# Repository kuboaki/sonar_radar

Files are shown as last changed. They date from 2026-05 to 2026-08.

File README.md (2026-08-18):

# sonar_radar

2D radar scanner using LEGO SPIKE Prime + Raspberry Pi Build HAT via [libspikehat](https://github.com/kuboaki/libspikehat).

This project is developed as a **digital twin**: the same application code
(`raspi/sonar_radar.py`) runs either on the real hardware or in a MuJoCo
simulation (`sim/sonar_radar_sim.py` + `libspikehat_sim`), so new behavior
can be developed and tuned in simulation before running it on the real robot.

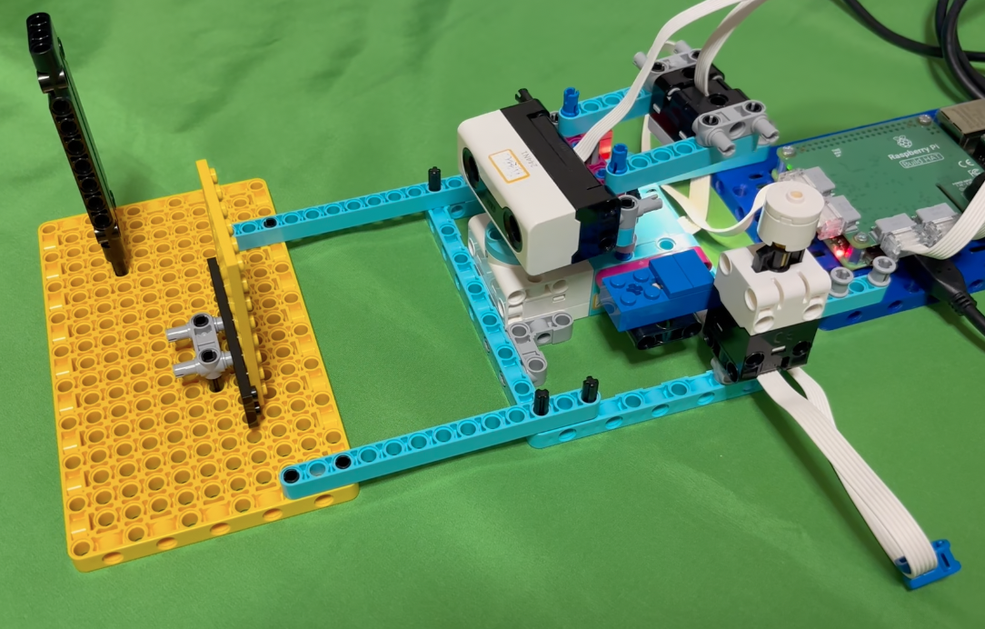
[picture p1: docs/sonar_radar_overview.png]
sonar_radar overview


[日本語版 README](README_ja.md)

## Hardware Configuration

| Port | Device | Role |
|---|---|---|
| A (0) | SPIKE Prime L Angular Motor | Dome rotation (1:3 reduction gear, direction-reversed) |
| B (1) | SPIKE Prime Force Sensor | Scan stop switch |
| C (2) | SPIKE Prime Color Sensor | End-stop marker detection (green = left end, blue = right end) |
| D (3) | SPIKE Prime Distance Sensor | Obstacle measurement |

### Rotation Markers

- **Green marker** — left end (negative direction) (formerly red; changed 2026-08-11 after real-hardware
  measurements showed hue chattering near the threshold and false-positive detection against a brown
  chassis part)
- **Blue marker** — right end (positive direction)

The dome scans back and forth, reversing direction whenever it detects either marker,
until the force sensor (stop switch) is pressed.

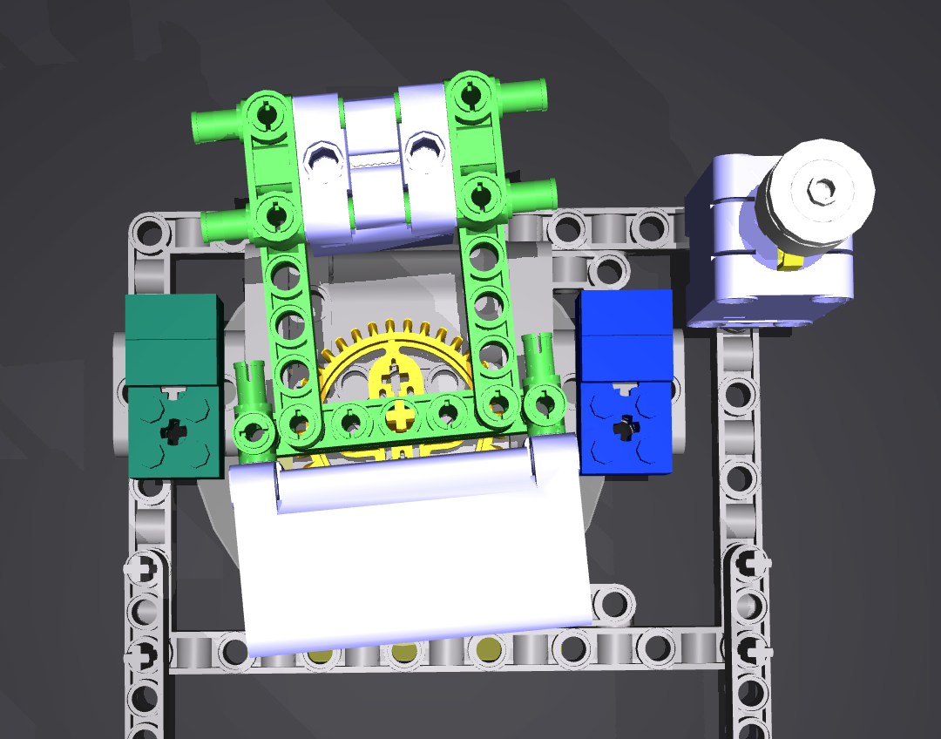
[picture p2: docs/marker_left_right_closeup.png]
Marker mechanism close-up: green marker at the left end, blue at the right end


## Scan Specification

| Parameter | Value |
|---|---|
| Sampling interval | 50 ms |
| Valid distance | 50–300 mm |
| Origin (0°) | Front center (calibrated at startup) |

## Running on the Real Hardware

- Raspberry Pi 4 + Build HAT
- **Raspberry Pi OS Bookworm (64-bit)**
- [libspikehat](https://github.com/kuboaki/libspikehat) built and installed
- `python3-build-hat` installed (`sudo apt install python3-build-hat`)

```bash
cd raspi
bash run.sh
```

`run.sh` loads the Build HAT firmware before running `sonar_radar.py`.
Avoid calling `sonar_radar.py` directly.

## Running in Simulation (MuJoCo)

- macOS / Linux with `mujoco` and `libspikehat_sim` installed (see `sim/libspikehat_sim/`)
  - **Important**: the `mujoco` pip package version must match `/Applications/MuJoCo.app`.
    A version mismatch causes a crash in `mj_ray` due to `mjModel` ABI incompatibility.
    Example: MuJoCo.app 3.10.0 → `pip install mujoco==3.10.0`, then rebuild `libspikehat_sim`.
- For viewer mode on macOS, use `mjpython` (required by MuJoCo's passive viewer)

```bash
cd sim
python3 sonar_radar_sim.py            # batch run (prints JSON result to stdout)
mjpython sonar_radar_sim.py --viewer  # with 3D viewer, real-time
```

`sonar_radar_sim.py` injects a simulated `spikehat` module backed by MuJoCo
and then runs `raspi/sonar_radar.py` unmodified — any change made to
`sonar_radar.py` is immediately reflected in the simulation. The simulation
always runs at real-time speed (`--speed 1.0`, fixed) so its behavior can be
compared directly against the real hardware.

The viewer's left UI panel is hidden by default for a cleaner view; interact
with the simulation using keyboard shortcuts instead: `Space` presses the
start/stop switch, `1`/`2` select the yellow/black obstacle wall, and the
arrow keys move the selected wall (left/right = X, up/down = Y). See
[mujoco_model/studio_to_mujoco.md](mujoco_model/studio_to_mujoco.md) for how
the MuJoCo model itself is built from the Bricklink Studio design.

#### Non-interactive run (automatic button injection)

Use `--auto-start` / `--auto-stop` to run the full scan without pressing the
physical force sensor — useful for CI and scripted testing:

```bash
# start 0.5 s after calibration, stop 3 s after start
python3 sim/sonar_radar_sim.py --auto-start 0.5 --auto-stop 3

# accelerated: 200× real-time for quick smoke tests
SPIKEHAT_SIM_SPEED_SCALE=200 python3 sim/sonar_radar_sim.py --auto-start 0.5 --auto-stop 3
```

| Option | Description |
|---|---|
| `--auto-start SEC` | Inject start button SEC seconds after calibration completes |
| `--auto-stop SEC`  | Inject stop button SEC seconds after scan start |

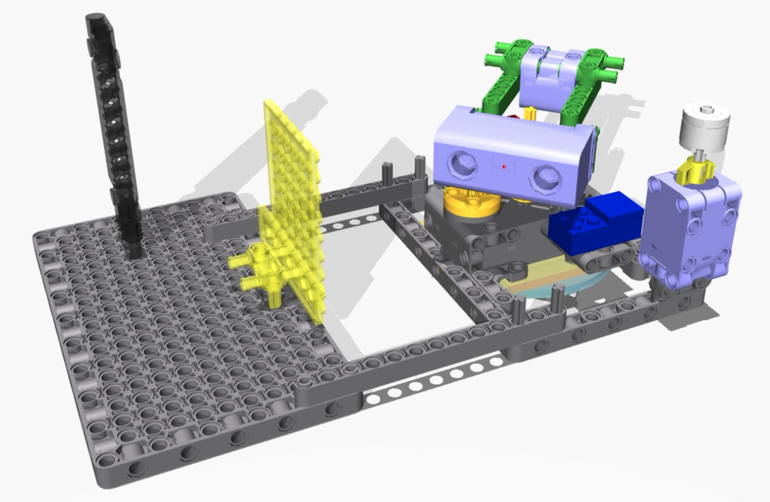
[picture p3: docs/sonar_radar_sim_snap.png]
シミュレーション実行中


*シミュレーション実行中*

## Output

JSON array to stdout, log to stderr:

```json
[
  {"angle": 12, "dome_angle": -4.0, "distance_mm": 136},
  {"angle": 15, "dome_angle": -5.0, "distance_mm": 135},
  {"angle": 21, "dome_angle": -7.0, "distance_mm": null},
  ...
]
```

- `angle` — motor encoder angle (degrees, relative to calibrated zero)
- `dome_angle` — dome angle (degrees, `angle / -3`)
- `distance_mm` — `null` when no object is detected within the valid range

## Visualization

`raspi/sonar_plot.py` reads the JSON output and plots `dome_angle` vs
`distance_mm` as a fan-shaped polar plot and a line plot, overlaying each
back-and-forth scan pass in a different color:

```bash
python3 raspi/sonar_radar.py > scan.json
python3 raspi/sonar_plot.py scan.json -o scan_result.png --title "scan result"
```

| Real hardware (`docs/scan_real.json`) | Simulation (`docs/scan_sim.json`) |
|---|---|
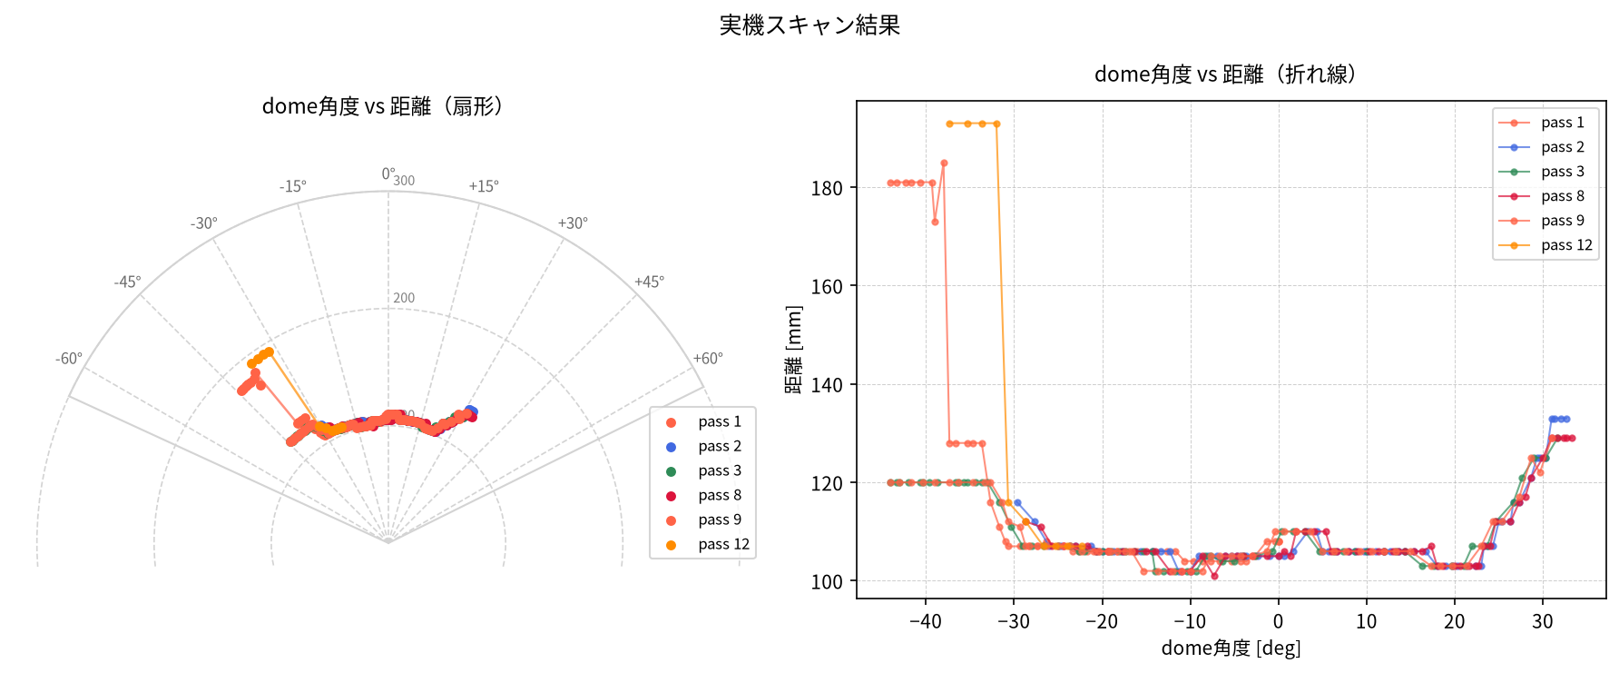
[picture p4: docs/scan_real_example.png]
real scan example
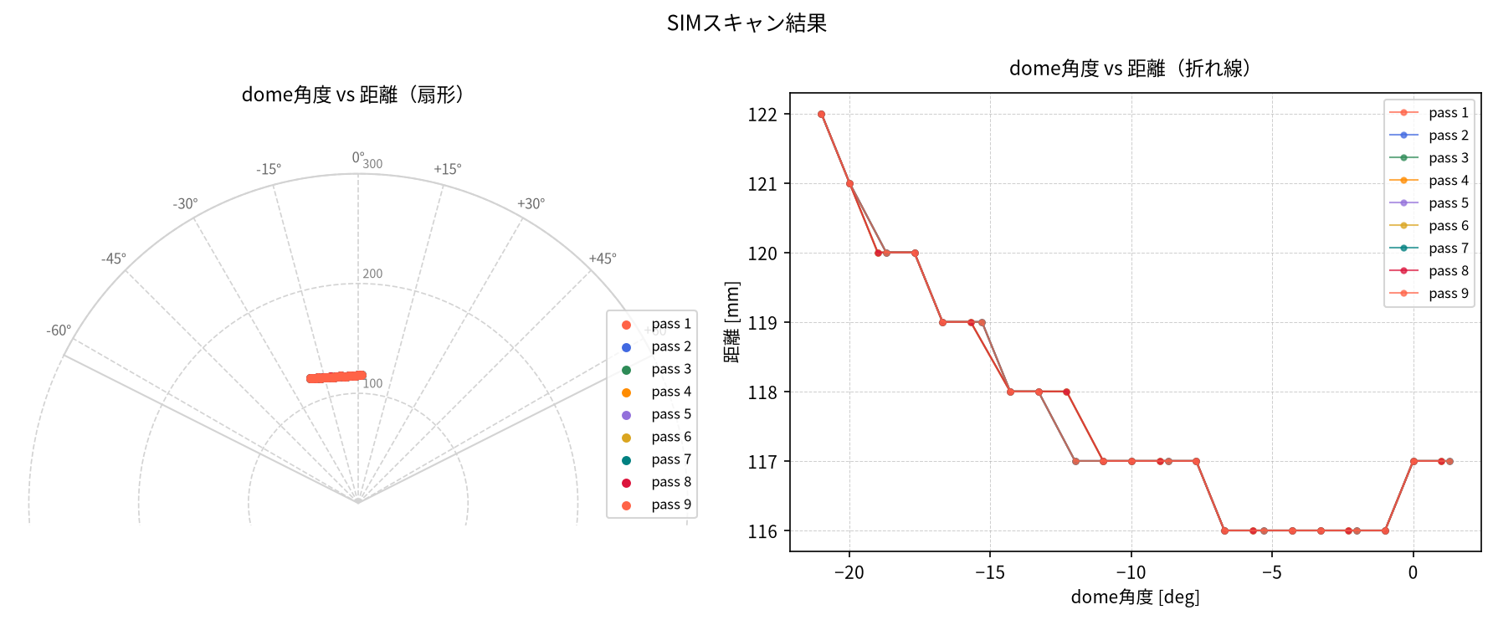
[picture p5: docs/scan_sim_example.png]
sim scan example
|  |  |

The real ultrasonic distance sensor has a wide beam, so it detects the wall
across a wide angular range (roughly -45° to +35° here). The simulated
distance sensor uses a single raycast, so it only detects the wall in a
narrow angular range directly in front (roughly -21° to +1° here). This FOV
discrepancy between the real sensor and the simulation is a known, currently
unaddressed difference (see [mujoco_model/studio_to_mujoco.md](mujoco_model/studio_to_mujoco.md)).

See [docs/visualization.md](docs/visualization.md) for the procedure used to
collect the real/sim scan data and generate these plots.

## Calibration

On startup, the motor moves to its mechanical zero position, then rotates by
`SENSOR_HOME_OFFSET` to compensate for the gear meshing offset, so that the
dome faces front (0°). No manual pre-positioning is required.

## Project Structure

```
sonar_radar/
├── raspi/                  Real-hardware app (run on Raspberry Pi)
│   ├── sonar_radar.py    Main scanner script (shared with simulation)
│   └── run.sh              Startup script (loads firmware + runs scanner)
├── sim/                     MuJoCo simulation
│   ├── sonar_radar_sim.py  Entry point that runs sonar_radar.py via libspikehat_sim
│   └── libspikehat_sim/    MuJoCo-based simulation library (libspikehat API)
├── mujoco_model/            MuJoCo model (XML, meshes, Blender export scripts)
│   └── studio_to_mujoco.md  Bricklink Studio → MuJoCo model build guide
├── studio_model/            Bricklink Studio model files
└── docs/                    Documentation images
```

## License

MIT License

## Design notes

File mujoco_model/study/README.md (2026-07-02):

# study/ — センサーコンポーネント include 方式への移行検討資料

このディレクトリには、distance_sensor および color_sensor を
libspikehat_sim の `<include>` コンポーネント方式に移行するにあたり
作成した検討・検証用の MuJoCo モデルを保存しています。

同様の作業を新しいプロジェクトで行う際の参考にしてください。

---

## 背景と問題意識

### インライン版の問題

移行前は、センサーの `<inertial>` / `<geom>` / `<site>` を
sonar_radar.xml に直接書く「インライン版」を使っていた。

インライン版の欠点:
- 複数モデルで同じセンサーを使う場合に XML が重複する
- センサー仕様が変わったときに全モデルを手修正する必要がある
- STL の座標系規約がモデルごとに異なり、位置合わせが困難になる

### include 方式の採用

libspikehat_sim の `examples/components/` 以下に
`distance_sensor_body.xml` / `color_sensor_body.xml` を置き、
利用側モデルは `<include file="..."/>` で取り込む方式に統一した。

---

## MuJoCo `<include>` の重要な挙動

MuJoCo の `<include>` は **ルート `<body>` タグを除去** し、
その子要素（`<inertial>` / `<geom>` / `<site>`）のみを
親 body に挿入する。

```xml
<!-- color_sensor_body.xml の内容 -->
<body name="color_sensor" euler="-90 0 0">   ← このタグは除去される
  <inertial .../>
  <geom .../>
  <site .../>
</body>
```

```xml
<!-- 利用側モデル -->
<body name="color_sensor" pos="X Y Z" euler="-90 0 0">  ← euler はここに書く
  <include file=".../color_sensor_body.xml"/>
</body>
```

**euler や joint は必ず外側の body に書くこと。**
コンポーネントファイル内のルート body の euler は無視される。

---

## STL 座標系規約: pivot_origin 方式

distance_sensor / color_sensor ともに `pivot_origin` 方式を採用している。

- STL の原点 = LDraw パーツの基準点（ピボット）
- Blender でインポートする際は `.io` ではなく `.ldr` を直接インポートする
  （Studio の床スナップで Z=19.5 LDU がつくため）
- blender_export_*.py の `center_mode="pivot_origin"` で生成する

`bottom_z`（STL 底面 Z=0）方式も試みたが、
モデルによってパーツの底面定義が異なり、汎用コンポーネントに向かないため廃止。

---

## ドームの5°傾き補正

sonar_radar のドームは、LDraw ジオメトリレベルで5°傾いている
（LDraw 上のボディ配置ではなくメッシュ形状に焼き込まれている）。

そのため、ドーム上のすべてのセンサーの euler に
**親フレーム（gear36）での Rz(+5°) 前置乗算** が必要になる。

### distance_sensor の場合

`blender_export.py` の `compute_local_body_euler()` が
ドームの実姿勢を含む world 回転を計算するため、
Blender 上で5°傾きが自動的に捉えられた。

結果: `euler="0 0 -175"` （-180° + 5° の補正）

### color_sensor の場合

Blender 上での計算結果は `euler="-90 -180 0"` （5°成分なし）だった。
これはカラーセンサーの LDraw 配置がドーム傾きを陽に反映していないため。

手動で Rz(+5°) を親フレームで前置乗算して euler を再計算した:

```
R_corrected = Rz(+5°) × Rx(-90°) × Ry(-180°)
→ euler="90 5 180"  （XYZ 分解結果）
```

**注意**: Rz(+5°) を XYZ euler の Rz 成分（第3引数）に加算するだけでは誤り。
intrinsic（ボディフレーム）回転になってしまい、親フレームでの補正にならない。

---

## 検証用モデルの説明

### test_distance_include_rotation.xml

distance_sensor を `<include>` 方式で単体検証するモデル。
gear36 相当のダミー body を原点に置き、その子として
sonar_sensor を配置してビューアで向きを確認するために使った。

pos / euler は最終的に sonar_radar.xml に採用した値と異なる場合がある
（試行錯誤の途中段階のものが残っている）。

### test_old_vs_new_sensor.xml

距離センサーの「インライン版（旧）」と「include 版（新）」を
ドームメッシュと一緒に同じシーンに並べて位置を比較したモデル。

- 旧インライン版: 緑色（rgba 0.2 0.9 0.2）
- 新 include 版:  赤色（include 版は色変更できないため構造で識別）

include 版の pos をインライン版に合わせ込む作業に使った。

---

## 今後の新プロジェクトへの適用手順

1. Studio でロボットモデルにセンサーを配置した `.io` を作成
2. Blender で `.ldr`（Studio 床スナップ対策、手動で Z=0 維持）をインポート
3. `blender_export_*.py` を実行して STL と pos/euler を取得
4. 利用側モデルで outer body に pos/euler を設定し `<include>` を挿入
5. ドーム等の傾きがある場合は親フレームでの回転補正を手計算で追加
6. ビューアで視覚確認し、site（黄色球）が検出面から見えることを確認

詳細は `libspikehat_sim/docs/` も参照すること。

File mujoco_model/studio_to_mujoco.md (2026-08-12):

# Bricklink StudioのモデルをMuJoCoで使う

## 概要

Bricklink Studioで作成したLEGOモデルをMuJoCo物理シミュレーターで使うための手順をまとめる。
ここでは、ソナーレーダーモデル（`sonar_radar`）を例に説明する。

```
Studio (.io) → Blender → STLメッシュ → MuJoCo XML（配置調整）→ Control割り当て → ビューア設定
```

最終的な目的は「実機の開発をシミュレータ上のコード(`raspi/sonar_radar.py`)で行い、
そのコードをそのまま実機(`libspikehat`)に持っていって動かす」こと。
そのためMuJoCoモデル側は、`libspikehat_sim` が要求するjoint/site/sensor構成
（[9. libspikehat_simとの連携](#9-libspikehat_simとの連携)参照）に適合させる必要がある。

---

## 1. Bricklink Studioでモデルを作成する

### 1.1 サブモデルの設計方針

MuJoCoで扱いやすくするため、Studioのモデル設計時に以下の点を考慮する。

**可動部はサブモデルに分ける**

MuJoCoのジョイント（関節）は body の階層で表現する。Studioでも同様に、動く部分を別サブモデルとして分離しておく。

例：
- `radar_base` … 台座（固定）
- `radar_dome` … ドーム一式（旋回する）
- `bevel_gear_12` … モーター側の12Tベベルギア（旋回する）

**色を使う部分（マーカーなど）もサブモデルに分ける**

MuJoCoのSTLメッシュは単色しか指定できない。複数色を再現するには、色ごとにSTLを分けてgeomを複数定義する必要がある。そのため、色の異なるパーツは別サブモデルとして分離しておく。

例：
- `marker_left` … 左限界マーカーブロック（`39789.dat` + ブッシュ `3713.dat`）。検出時にドームは左限界(9時方向)を向いている
- `marker_right` … 右限界マーカーブロック（`39789.dat` + ブッシュ `3713.dat`）。検出時にドームは右限界(3時方向)を向いている

> **命名は色ではなく機能(検出時のドーム旋回限界)を基準にする。** `sonar_radar09`までは`marker_red`/`marker_blue`という色ベースの命名だったが、実機実測(2026-08-11)でマーカー色を赤→緑に変更した際、色名と実際の色が食い違う問題が起きた。`sonar_radar10`で`marker_left`/`marker_right`(色を検出したときにドームがどちらの旋回限界にいるかを表す)へリネームし解消した。マーカー自体の物理的な設置位置(左/右)ではなく、検出結果としての意味(旋回限界)を基準にしている点に注意(12時方向を超音波センサー正面としたとき、緑マーカーは3時側=物理的には右に設置されているが、緑を検出する = ドームが9時側=左限界にある、という対応)。

> **注意：** Studioでは単一ブロックのサブモデルは作成できない。ブッシュなど固定パーツと組み合わせてサブモデルにする。

**ギアでつながる回転部品は、それぞれ独立したサブモデルにする**

`sonar_radar07` では、モーター側の12Tベベルギア（`bevel_gear_12`）とドーム側の36Tベベルギア
（ドーム一式に内包）が別々に回転する。MuJoCo側ではこれを2つの独立したhinge jointとし、
`equality`制約でギア比・回転方向を結びつける（[6.3](#63-equality制約によるギア連動)参照）。
そのため、Studio側でもこの2つを別サブモデルとして分離しておく。

> 旧版（`sonar_radar06`）ではモーター本体とローターを一体のカスタムパーツ
> （`motor_body`/`motor_rotor`）として作成していたが、現行版ではモーター本体側の
> メッシュは `libspikehat_sim/examples/test_motor.xml` 側に切り出され、
> `sonar_radar.xml` には含まれない。

### 1.2 サブモデルの構造例（sonar_radar10）

```
sonar_radar10.io
├── radar_base          … 台座グレーパーツ
│   ├── marker_right    … 右限界マーカー（サブモデル。命名基準は1.1節参照）
│   │   ├── 3713.dat    … ブッシュ（グレー）
│   │   └── 39789.dat   … マーカーブロック（青）
│   └── marker_left     … 左限界マーカー（サブモデル）
│       ├── 3713.dat    … ブッシュ（グレー）
│       └── 39789.dat   … マーカーブロック（緑）
├── radar_dome          … ドーム一式（36Tベベルギア32498.dat、距離/カラーセンサー含む）
├── bevel_gear_12       … モーター側12Tベベルギア（旋回軸=このサブモデル原点）
├── obstacle_wall_a     … 障害物壁A（黄色、独立サブモデル）
└── obstacle_wall_b     … 障害物壁B（黒、独立サブモデル）
```

---

## 2. Blenderの準備

### 2.1 使用するアドオン

**ldr_tools_blender**（by ScanMountGoat）

- リポジトリ：https://github.com/ScanMountGoat/ldr_tools_blender
- LDraw形式（`.ldr`、`.mpd`）およびBricklink Studioの `.io` ファイルをBlenderにインポートするアドオン
- Blender 4.1以降に対応（リリースはBlenderのPythonバージョンに紐付き）
- Rustベースの高速実装

**インストール手順：**

1. GitHubの [Releases](https://github.com/ScanMountGoat/ldr_tools_blender/releases) ページから使用しているBlenderバージョンに対応したzipをダウンロード（zipは展開しない）
2. Blenderを起動し、`Edit → Preferences → Add-ons → Install` を開く
3. ダウンロードしたzipファイルを選択してインストール
4. アドオン一覧で `ldr_tools_blender` を検索してチェックを入れて有効化

> **アップグレード時の注意：** 旧バージョンをアンインストールしてから新バージョンをインストールする必要がある。

### 2.2 デフォルトオブジェクトの削除

Blenderを新規起動すると、デフォルトでカメラ・ライト・キューブが挿入されている。ioファイルをインポートする前に、これらをすべて削除しておく。

```
Edit → Delete All（またはシーン内のオブジェクトをすべて選択してDelete）
```

### 2.3 アドオンの設定（ldr_tools_blender）

`File → Import → LDraw` を選択すると、ファイルダイアログの左側にインポートオプションパネルが表示される。以下の項目を設定する。

#### LDraw Library（LDrawライブラリのパス）

LDrawパーツライブラリの場所を指定する。Studioのアプリケーションフォルダ内のものをそのまま使用できるため、別途ダウンロードは不要。

- Mac: `/Applications/Studio 2.0/ldraw`

#### Additional Library Path（追加ライブラリのパス）

Studioで作成したカスタムパーツ（モーターローターなど）の格納場所を指定する。

- Mac: `/Users/<ユーザー名>/.local/share/Stud.io/CustomParts/`

> Macでは `.local` は隠しディレクトリのためFinderでは非表示。パス入力欄に直接入力する。
>
> **注意（2026-08-12訂正）**: アプリのサポートフォルダ名は`Studio.io`ではなく`Stud.io`（`i`の後にピリオドが入らない）。誤ったパス（存在しないディレクトリ）を指定すると、カスタムパーツ（モーターローター等）が無言でスキップされ、インポート後のBlenderシーンにモーターが表示されない、という気づきにくい壊れ方をする（エラーダイアログ等は出ない）。「モーターが消えた」と感じたら、まずこのパス設定を確認すること。

#### その他のパラメータ

| パラメータ | 設定値 | 備考 |
|---|---|---|
| Instance Type | **Linked Duplicates** | 同種パーツがメッシュを共有し軽量化される |
| Stud Type | **Normal** | 標準のスタッド形状 |
| Resolution | **Low** | ポリゴン数を抑える（MuJoCo用途では十分） |
| Gap Between Parts | **チェックあり** | パーツ間に微小な隙間を入れる（実物に近い見た目） |
| Scale | **1.0** | スケール変換はエクスポートスクリプト側で行うため、Blender上は原寸のまま |

> **Scaleを1.0にする理由：** Blenderインポート時にスケールを変えると `matrix_world` による頂点座標変換が複雑になる。エクスポートスクリプト内で `SCALE = 0.0004`（LDU→メートル）を適用するため、Blender上は原寸（LDU単位）のまま扱う。

---

## 3. BlenderへのioファイルのインポートとSTL生成

### 3.1 インポート手順

1. Blenderを起動し、デフォルトオブジェクトを削除
2. `File → Import → LDraw` で `.io` ファイルを選択
3. Scale=1 でインポート
4. アウトライナーでサブモデルの階層構造を確認

### 3.2 インポート後のオブジェクト階層

インポートすると、Studioのサブモデル構造がBlenderのオブジェクト階層として反映される。

```
sonar_radar07.io  [EMPTY]
├── radar_base       [EMPTY]
│   ├── 32054.dat    [MESH]
│   ├── ...
│   ├── marker_right [EMPTY]
│   │   ├── 3713.dat  [MESH]
│   │   └── 39789.dat [MESH]
│   └── marker_left  [EMPTY]
│       ├── 3713.dat.001  [MESH]
│       └── 39789.dat.001 [MESH]
├── radar_dome       [EMPTY]
│   ├── 32498.dat    [MESH]  ← 36Tベベルギア（旋回軸原点）
│   ├── 37316c01.dat [MESH]  ← 距離センサー
│   ├── 37308c01.dat [MESH]  ← カラーセンサー
│   └── ...
└── bevel_gear_12    [EMPTY]
    └── ...（12Tベベルギア本体、旋回軸=このEMPTYの原点）
```

---

## 4. Blenderスクリプトによる変換（blender_export.py）

### 4.1 スクリプトの概要

`blender_export.py` をBlenderのスクリプトエディタで実行することで、MuJoCo用のSTLメッシュファイルと、
MJCFに貼り付けるためのpos値・site値をログに出力する。

### 4.2 座標変換の処理

LDraw座標系からMuJoCo座標系への変換を以下の手順で行う。

1. **ワールド座標に変換**
   `matrix_world` を使って各頂点をBlenderのワールド座標に変換する

2. **オフセット適用**
   `center_mode` に応じてオフセットを計算する（詳細は4.3）

3. **LDraw → MuJoCo座標変換 + スケール適用**
   ```python
   mj_x = -rx * SCALE   # SCALE = 0.0004 (LDU → m)
   mj_y = -ry * SCALE
   mj_z =  rz * SCALE
   ```

4. **quad → 三角形分割**
   MuJoCo（STL）は三角形ポリゴンのみ対応のため、四角形ポリゴンをfan分割する

### 4.3 オフセットの種類（center_mode）

| center_mode | 内容 | 用途 |
|---|---|---|
| `bottom_z` | XY中心化＋Z底面=0 | 単独の固定パーツ |
| `center` | XYZ中心化 | フォールバック |
| `rotor_axis` | 指定オブジェクトの原点を基準 | 旋回するパーツ（`radar_dome`, `bevel_gear_12`） |
| `shared` | 呼び出し側で計算した共通オフセットを使用 | `radar_base`（gray/red/blue で位置関係を保つ） |

`radar_dome` は `32498.dat`（36Tベベルギア）、`bevel_gear_12` はサブモデル自身の原点を
`rotor_axis_obj` として渡す。これにより、STLの原点がそのままMuJoCoの `joint` 位置（hingeの回転軸）
と一致するため、MJCF側で `body pos` を「joint位置」として扱える。

### 4.4 サブモデル境界の扱い（stop_at_empty）

`radar_base` のSTL生成時は、`marker_left`/`marker_right` のメッシュを誤って含めないよう
`stop_at_empty=True` を指定する。これにより、EMPTY（サブモデル境界）に到達したところで
再帰収集を停止する。

### 4.5 色別STL分割（radar_base）

マーカーブロックの色を再現するため、`radar_base` を3つのSTL（gray/red/blue）に分割する。
gray/red/blueの3つは、全パーツの統合bboxから計算した共通オフセット（`shared_offset`）を使う。
これにより3つのSTLの位置関係が正しく保たれ、MuJoCo上で重ね合わせたときに一致する。

### 4.6 センサーsite位置の自動計算

`radar_dome` エクスポート時、`32498.dat`（旋回軸）を基準に、距離センサー（`37316c01.dat`）と
カラーセンサー（`37308c01.dat`）のローカル座標を計算し、`<site>` タグの形でログに出力する
（`compute_local_site_pos`）。

```
<site name="sonar_site" pos="..." size="0.01" rgba="1 0 0 1"/>
<site name="color_site" pos="..." size="0.01" rgba="1 1 0 1"/>
```

これは**初期値**であり、実際にはビューアで実機の検出結果と見比べながら微調整する
（[7. センサーsiteの配置調整](#7-センサーsiteの配置調整)参照）。

### 4.7 スクリプトの実行方法

1. Blenderのスクリプトエディタで `blender_export.py` を開く
2. 「スクリプトを実行」ボタンをクリック
3. `blender_export_log.txt` で結果（オフセット値、MJCF pos、site pos、XMLスニペット）を確認

---

## 5. 生成されるファイル

### 5.1 STLメッシュファイル（meshes/フォルダ）

| ファイル | 内容 | rgba |
|---|---|---|
| `radar_base_gray.stl` | 台座グレーパーツ | `0.366 0.361 0.371 1` |
| `radar_base_left.stl` | 左限界マーカーブロック(緑検出時。旧`radar_base_red.stl`/`base_red_geom`。実機実測(2026-08-11)でチャタリング・誤検出が判明し赤→緑に変更、2026-08-12にsonar_radar10でファイル名・geom名も`left`/`right`(機能ベース)にリネーム) | `0.020 0.250 0.200 1`(HSV変換でhue≈167、実機実測のhue158〜170に整合) |
| `radar_base_right.stl` | 右限界マーカーブロック(青検出時。旧`radar_base_blue.stl`/`base_blue_geom`) | `0.000 0.089 0.515 1` |
| `radar_dome.stl` | ドーム一式（36Tベベルギア含む） | `0.2 0.5 0.2 1` |
| `bevel_gear_12.stl` | モーター側12Tベベルギア | `0.9 0.7 0.1 1` |

### 5.2 ログファイル

- `blender_export_log.txt` … 座標変換のオフセット値、MJCF posの計算結果、site pos、XMLスニペットを出力

---

## 6. MuJoCo XMLへの組み込みと配置調整

### 6.1 body階層とSTLの対応

```
Studio サブモデル        MuJoCo XML
────────────────────    ──────────────────────────────────────────
radar_base           →  <body name="radar_base">
  marker_left        →    <geom name="base_left_geom" .../>  ※同じbody内に複数geom
  marker_right       →    <geom name="base_right_geom" .../>

bevel_gear_12        →  <body name="motor_rotor">           ← motor_joint(hinge)
                            <geom name="bevel_gear_12_geom" .../>

radar_dome           →  <body name="radar_dome">            ← dome_joint(hinge)
                            <geom name="dome_geom" .../>
  37316c01.dat       →    <body name="sonar_sensor" pos="..." euler="...">
                              <include file=".../distance_sensor_body.xml"/>
                            </body>
  37308c01.dat       →    <body name="color_sensor" pos="...">
                              <geom name="color_geom" .../>
                              <site name="color_site" .../>
                            </body>
```

`motor_rotor`（12Tギア）と `radar_dome`（36Tギア）は、いずれも `radar_base` の直下に
**独立した body** として配置し、それぞれに `hinge` jointを持たせる。2つのjointは
equality制約で連動させる（[6.3](#63-equality制約によるギア連動)）。

距離センサー（`37316c01.dat`）は `libspikehat_sim` のコンポーネント
（`distance_sensor_body.xml`）を `<include>` で組み込む。
カラーセンサー（`37308c01.dat`）は現状インラインSTLのまま（今後コンポーネント化予定）。

### 6.2 配置（pos/euler）はBlender出力どおりにならない

`blender_export_log.txt` に出力されるpos値（`rotor_axis`基準で計算した値）は**初期値**であり、
そのままではビューア上でパーツ同士の噛み合いや向きがズレることが多い。
実際には以下のような**手動調整が必須**になる。

- **回転方向（axis符号）の調整**
  Studio/Blender側のZ軸回転と、MuJoCo `euler`・`joint axis` の符号の関係は自明ではない。
  「正方向に回したらどちらに動くべきか」を実機と見比べ、`joint axis="0 0 1"` /
  `axis="0 0 -1"` のどちらにするかを決める
  （[[feedback_mujoco_hinge_axis_vs_equality_sign]] 参照：符号調整は
  equality制約側ではなく hinge axis 側で行うこと）。

- **ギアの噛み合い位置の微調整**
  `motor_rotor`（12T）と `radar_dome`（36T）はそれぞれ別サブモデルとしてエクスポートされた
  原点を基準に配置するが、Studio上の組み立て位置によっては数度ズレた状態でしか噛み合わない
  （sonar_radar07では実測5度のズレがあった）。この機構的なズレは
  `raspi/sonar_radar.py` 側の `SENSOR_HOME_OFFSET` で補正し、**MuJoCoモデル自体は
  組み立て可能な位置であればよい**、という方針にしている。

- **dome本体の位置(pos)**
  `radar_dome` の `pos` は、`bevel_gear_12`（motor_rotor）の旋回軸との相対位置になるよう
  ビューアで動かしながら微調整する。現在値は `pos="-0.0083 0.0007 0.0358"`。

### 6.3 equality制約によるギア連動

12T-36Tベベルギアの噛み合い（ギア比1:3、回転方向反転）は、2つのhinge jointを
`equality`制約の `polycoef` で結びつけて表現する。

```xml
<equality>
  <!-- ベベルギア(12T-36T)噛み合い: dome_joint = +motor_joint / 3
       motor_joint axis="0 0 -1"(正=CW), dome_joint axis="0 0 1"(正=CCW)
       CWモーターに対してCCWドーム → polycoef正 -->
  <joint joint1="dome_joint" joint2="motor_joint" polycoef="0 0.33333333 0 0 0"/>
</equality>
```

**motor/dome の axis 設定（sonar_radar08 実機確認済み）:**

| joint | axis | 正方向の意味 |
|---|---|---|
| `motor_joint`（12T, motor_rotor） | `0 0 -1` | 正 = CW（時計回り）= 実機の正エンコーダ方向 |
| `dome_joint`（36T, bevel_gear_36） | `0 0 1` | 正 = CCW（反時計回り）= 実機の正PWM時のドーム旋回方向 |

実機確認：正PWM → エンコーダ正 → モーターCW → ドームCCW（ベベルギアで逆転）。

> **回転方向の調整は `axis` で行う。** `polycoef` の符号を変えて回転方向を反転させると、
> 一見動くが速度比などで不整合が生じることがある。回転方向の反転は
> `<joint ... axis="0 0 -1" .../>` のように joint の `axis` 側で行い、
> `polycoef` はギア比（絶対値）のみを表す、という分担にする。

### 6.4 衝突ガードジオム

壁がモーター柱やドーム旋回範囲に侵入しないよう、`radar_base` body に薄いスラブ型
ガードジオムを追加する。

```xml
<!-- 高さ4mm（Z=0〜4mm）の薄スラブにして、センサーのレイキャスト高さ（30mm以上）に干渉しない -->
<geom name="radar_column_guard" type="box"
      pos="0.008 0.060 0.002" size="0.030 0.030 0.002"
      contype="1" conaffinity="1" rgba="0.9 0.5 0.1 0.3"/>
<geom name="dome_sweep_guard" type="cylinder"
      pos="0.0076 0.0728 0.002" size="0.040 0.002"
      contype="1" conaffinity="1" rgba="0.5 0.8 0.9 0.3"/>
```

> ガードを全高のboxやcylinderにすると `mj_ray`（NULL geomgroup）がセンサーレイキャストの
> 対象に含まれてしまい、カラーセンサーがマーカーより先にガードに当たる問題が発生する。
> `libspikehat_sim` 側にモデル固有の geomgroup フィルタを追加してはならない
> （汎用ライブラリとしての設計原則）ため、ガード側を薄くして高さで回避する。

---

## 7. センサーsiteの配置調整

`sonar_site`（距離センサー）・`color_site`（カラーセンサー）は、4.6で自動計算した値を初期値として、
以下の手順で実機に合わせて微調整する。

1. **初期配置**: `blender_export_log.txt` 出力値をXMLに貼り付ける
2. **静止状態での距離値の確認**: dome角度0°（正面）で `sonar_site` から壁までの距離を
   simで読み取り、実機の同条件での測定値（例: 実機118mm vs sim116mm）と比較してZ/Y位置を調整
3. **マーカー検出角度の確認**: `color_site` の位置・向きにより、赤/青マーカーを検出する
   dome角度がsim/実機で一致するかを確認し、位置を微調整する
4. **ビューアでの目視確認**: site（球で表示される）が実機の対応する部品（センサーブロック）の
   位置に重なっているかを目視で確認する

site位置の調整は、6.2の本体位置(pos)調整と相互に影響するため、
「本体位置を仮決め → site位置を実測値に合わせる → 旋回させて再確認」を繰り返す。

---

## 8. Controlの割り当て

ビューアの **Control** タブから操作できるアクチュエータと、`libspikehat_sim` が参照するsensorを
以下のように対応づける。

### 8.1 actuator一覧

| actuator | joint | 種別 | 用途 |
|---|---|---|---|
| `turret_motor` | `motor_joint` | motor（トルク, gear=10） | `motor_pwm`/`motor_run_to_position` で旋回 |
| `press_ctrl` | `press_slide` | position | 終了スイッチ(`press_body`)を押す（ビューア操作用） |
| `wall_a_x_ctrl` | `wall_a_x` | position | 壁A（黄色）のX位置（ビューア操作用） |
| `wall_a_y_ctrl` | `wall_a_y` | position | 壁A（黄色）のY位置（ビューア操作用） |
| `wall_b_x_ctrl` | `wall_b_x` | position | 壁B（黒）のX位置（ビューア操作用） |
| `wall_b_y_ctrl` | `wall_b_y` | position | 壁B（黒）のY位置（ビューア操作用） |

`turret_motor` のみがアプリケーションコード（`sonar_radar.py`）から操作される。
他は**ビューアのControlタブから人間が操作する**ためのもので、実機には存在しない
sim専用のオブジェクト（壁・終了スイッチ）を動かすために用意している。

**壁のキーボード操作（sonar_radar_sim.py）:**

| キー | 動作 |
|---|---|
| `1` | 壁A（黄色）を選択 |
| `2` | 壁B（黒）を選択 |
| `←` / `→` | 選択中の壁をX方向に1スタッド（8mm）移動 |
| `↑` / `↓` | 選択中の壁をY方向に1スタッド（8mm）移動 |

MuJoCo ビューアの組み込みショートカット（A/D/W/S/F 等）と競合するため、
WASDキーは使用しない。矢印キーは `key_callback` で `_KEY_RIGHT/LEFT/UP/DOWN`
（GLFW keycode 262〜265）として取得する。

### 8.2 sensor一覧

| sensor | 種別 | 対応するlibspikehat_sim API |
|---|---|---|
| `turret_angle`/`turret_vel` | jointpos/jointvel (`motor_joint`) | `motor_get_position` |
| `dome_angle`/`dome_vel` | jointpos/jointvel (`dome_joint`) | （デバッグ用、API未使用） |
| `distance_pos`/`distance_quat` | framepos/framequat (`distance_site`) | `distance_read`（前方レイキャスト） |
| `color_pos`/`color_quat` | framepos/framequat (`color_site`) | `color_read_hsv`/`color_read_rgb`（下方レイキャスト） |
| `force_touch` | touch (`force_site`) | `force_is_pressed` |

新しい実機を作る場合も、**アプリコードが使うAPIに対応するsite/sensorは必ず用意する**
（`motor_joint` + `sonar_site` + `color_site` + `force_site` 相当）。
壁や終了スイッチのような「sim専用の操作対象」は、実機に存在しなくても
ビューア確認用に追加してよい。

---

## 9. ビューアの設定（sonar_radar_sim.py）

`sim/sonar_radar_sim.py` がMuJoCoモデルとビューアを起動するランチャー。
モデル固有の設定は主に以下の3か所に集中している。

### 9.1 初期カメラ

floor(2m四方)を含めた自動フィットだと対象（数cm）が小さく表示されるため、
本体サイズを基準にカメラを寄せる。

```python
_mdl.stat.center[:] = [0.0, -0.02, 0.03]
_mdl.stat.extent = 0.12
...
viewer.cam.lookat[:] = _mdl.stat.center
viewer.cam.distance  = _mdl.stat.extent * 2.5
viewer.cam.azimuth   = 180.0
viewer.cam.elevation = -30.0
```

新しいモデルでは、本体のだいたいの中心座標とサイズに合わせて `stat.center`/`stat.extent` を変更する。

### 9.2 表示用 qpos の反映

表示専用の `_dat` には物理演算（mj_step）を行わず、メインスレッド側 `libspikehat_sim` の
実シミュレーション状態（`hat.motor_get_position` 等）を `mj_kinematics`/`mj_comPos` で
反映するだけにする。`equality`制約はここでは評価されないため、`dome_joint` の角度も
`motor_joint` の角度から `polycoef` と同じ式で手動計算している。

```python
_motor_rad = math.radians(_hat.motor_get_position(0))
_dat.qpos[_motor_qadr] = _motor_rad
_dat.qpos[_dome_qadr]  = +_motor_rad / 3.0   # equalityのpolycoefと同じ式（符号は6.3参照）
```

新しいモデルでギア比が変わる場合は、ここの係数も `polycoef` と合わせて変更する。

### 9.3 Controlタブの操作をsimに転送

`press_ctrl`/`wall_x_ctrl`/`wall_y_ctrl` のように、ビューアのControlタブで人間が操作する
sim専用actuatorは、表示用 `_dat.ctrl` の値を毎フレーム `hat.sim_set_ctrl()` で
実シミュレーション側に転送し、結果のqposを表示用 `_dat.qpos` に反映する。

```python
_hat.sim_set_ctrl(_press_aid, float(_dat.ctrl[_press_aid]))
...
_dat.qpos[_press_qadr] = _hat.sim_get_qpos(_press_qadr)
```

壁のように複数のsim専用オブジェクトがある場合は、それぞれに同様の転送処理を追加する。
壁の移動はControlタブのスライダーに加え、キーボードコールバック（`key_callback`）からも
`_dat.ctrl` を直接書き換えることで操作できる（8.1参照）。

新しいモデルでsim専用の可動オブジェクトを追加する場合は、対応するactuator/jointの
id取得とこの転送処理を追加する。

### 9.4 実行速度（speed_scale）

`--speed` のデフォルトは **1.0（実時間）固定**。実機の動作時間とsimの動作時間を
直接比較できることが本プロジェクトの前提のため、デフォルト値は変更しない
（[[feedback_sonar_radar_realtime_sim]] 参照）。

---

## 10. libspikehat_simとの連携

### 10.1 概要

`libspikehat_sim` は `libspikehat` と同じAPIを持つMuJoCo版シミュレーターライブラリ。
`sonar_radar.xml` に上記のsite/sensor/actuatorを用意することで、
`raspi/sonar_radar.py` をそのままsimで動かせる。

```
実機（Raspberry Pi）:  raspi/sonar_radar.py → libspikehat     → Build HAT → SPIKE Prime
シム（Mac/Linux）   :  raspi/sonar_radar.py → libspikehat_sim → MuJoCo   → mujoco_model/sonar_radar.xml
```

### 10.2 sonar_radar_sim.py の仕組み

`sim/sonar_radar_sim.py` が `libspikehat_sim` の `SpikeHat` を `spikehat.SpikeHat` として
`sys.modules` に差し込み、`raspi/sonar_radar.py` を `importlib` で `__main__` として実行する
（ファイルのコピーではなく、`raspi/sonar_radar.py` を直接参照する）。

### 10.3 実行方法

```bash
cd sonar_radar/sim
python3 sonar_radar_sim.py                 # バッチ実行（実時間）
mjpython sonar_radar_sim.py --viewer       # ビューア付き（推奨、実時間）
```

`SPIKEHAT_SIM_XML` 環境変数でXMLパスを上書きできる（デフォルトは
`mujoco_model/sonar_radar.xml`）。

### 10.4 libspikehat_sim コンポーネントの include と可動部アタッチメント

#### MuJoCo `<include>` の制約

MuJoCo の `<include>` はXMLを**そのまま埋め込む**仕組みであり、
Unreal Engine や Unity のようなコンポーネントシステムとは異なる。
include 内で定義されたボディに、include を利用する側から**子ボディを追加することはできない**。

```xml
<body name="sensor_mount">
  <include file=".../force_sensor_body.xml"/>
  <!-- force_sensor_body.xml の中にある button body に、
       ここから子ボディを追加することはできない -->
</body>
```

#### include に適したコンポーネント

外部パーツが可動部に接続**しない**センサー類は include に適している。

| コンポーネント | include 適合 | 理由 |
|---|:---:|---|
| `distance_sensor_body.xml` | ✓ | ドームに取り付くだけ（可動部への接続なし） |
| `color_sensor_body.xml` | ✓ | 同上 |
| `force_sensor_body.xml` | △ | button body に press_block が接続する |

#### 可動部に外部パーツを接続する場合

press_block（シャフトを含む）のように、コンポーネント内の可動ボディに**剛体結合**する
外部パーツは、MuJoCo の `weld` equality + tight solref で近似する。

```xml
<!-- press_block を button に剛体結合（include の制約によりボディ階層での表現不可） -->
<equality>
  <weld body1="press_block" body2="button" solref="0.001 1"/>
</equality>
```

- `solref="0.001 1"` はデフォルト (`0.02 1`) より大幅に拘束を強め、残差を最小化する。
- 完全剛体ではないため、高速・高荷重の用途には注意が必要。

#### インライン展開による回避

どうしても親子階層で剛体結合する必要がある場合は、
include を使わず force_sensor_body.xml の内容を利用側XMLにインライン展開し、
press_block を button ボディの子として直接定義する。

```xml
<body name="button" pos="0 0 0">
  <joint name="button_slide" .../>
  <geom name="button_geom" .../>
  <body name="press_block" pos="...">   <!-- シャフトごと button の子として定義 -->
    <inertial .../>
    <geom name="press_geom" .../>
  </body>
</body>
```

この場合、force_sensor_body.xml の更新を手動でインライン版に反映する必要がある。

---

## 11. Studioモデルを変更したときの影響範囲

Studioモデルを変更した場合、変更の種類によって必要な作業が異なる。

### 11.1 影響範囲サマリー

| 変更の種類 | STL再生成 | XML変更 | アプリコード変更 |
|---|:---:|:---:|:---:|
| 固定部品の追加・削除 | 要 | 不要 | 不要 |
| 可動部の形状変更 | 要 | 要（pos） | 不要 |
| センサーの取り付け位置変更 | 要 | 要（site） | 不要 |
| ギア比の変更 | 要 | 要（equality） | 要（3箇所） |
| 新しい可動部の追加 | 要 | 要（joint等） | 要（sim.py） |

### 11.2 変更別の作業内容

#### 固定部品の追加・削除（例：台座に飾りパーツを追加）

1. `blender_export.py` を再実行してSTLを再生成
2. `radar_base_gray.stl` 等を使い続ける場合はXML変更不要（自動反映）
3. ただし `shared_offset`（全パーツのbboxから計算）が変わるため、
   赤・青マーカー等の位置関係がずれていないかビューアで確認する

#### 可動部の形状変更（例：ドーム形状を変更）

1. 対応するSTLを再生成（例：`radar_dome.stl`）
2. `body pos` の再調整が必要になる場合あり（重心・サイズの変化による）
3. センサーsite（`sonar_site`/`color_site`）の位置を再確認・微調整
   （[7. センサーsiteの配置調整](#7-センサーsiteの配置調整)の手順を再実施）

#### センサーの取り付け位置変更（例：距離センサーの位置を変える）

距離センサーは `libspikehat_sim` のコンポーネント（`include`）として組み込んでいる。
位置変更時は以下の手順を踏む：

1. `sonar_radar09.io` でセンサーの取り付け位置・向きを変更して保存
2. Blenderで `sonar_radar09.io` をインポートし、センサー (`37316c01.dat`) と
   基準ボディ (`bevel_gear_36` 等) の `matrix_world.translation` を取得
3. `pos = -(T_sensor - T_ref) * SCALE`（mj_x,mj_y符号反転、mj_z符号そのまま）を計算
4. `sonar_radar.xml` の `sonar_sensor` body の `pos` を更新
5. `euler` は `R_sensor_world @ Rx(-90°) @ Rz(180°)` をT_conj変換して求める
   （`studio_to_mujoco.md` 付属の変換スクリプトを参照）

カラーセンサーは現状インラインSTLのため従来通り `blender_export.py` を再実行。

#### ギア比の変更（例：12T-36T → 12T-24T）

影響が最も広い。以下の3箇所を**一致させる**こと。

| ファイル | 変更箇所 | 例（1:2に変更） |
|---|---|---|
| `mujoco_model/sonar_radar.xml` | `<equality>` の `polycoef` | `"0 -0.5 0 0 0"` |
| `sim/sonar_radar_sim.py` | `_viewer_loop` 内のドーム角度計算 | `-_motor_rad / 2.0` |
| `raspi/sonar_radar.py` | `GEAR_RATIO` 定数 | `GEAR_RATIO = 2` |

> **注意：** 回転方向の反転は `polycoef` の符号ではなく `dome_joint` の
> `axis` で調整する（[[feedback_mujoco_hinge_axis_vs_equality_sign]]）。

#### 新しい可動部の追加（例：新センサーを別軸で追加）

1. Studio側でサブモデルを追加・STLを再生成
2. XMLに `<body>` / `<joint>` / `<actuator>` / `<sensor>` を追加（§6〜§8参照）
3. `sim/sonar_radar_sim.py` の `_viewer_loop` に新しいjoint/actuatorの
   id取得とqpos反映処理を追加（§9.2〜9.3参照）
4. 新センサーを `raspi/sonar_radar.py` から使う場合はアプリコードも更新

---

## 12. 変更履歴

### v0.11.0（2026-08-12）

**マーカーのサブモデル名を色ベース→機能ベースに統一（Left/Right命名統一）**

- Studio(`sonar_radar10.io`)で`marker_red`/`marker_blue`を`marker_left`/`marker_right`にリネーム。命名基準は「色を検出したときドームがどちらの旋回限界にいるか」（1.1節の注記参照。マーカー自体の物理設置位置とは対応が逆転する点に注意）。
- `blender_export.py`のオブジェクト参照・出力STLファイル名を追従（`radar_base_red.stl`/`radar_base_blue.stl` → `radar_base_left.stl`/`radar_base_right.stl`）。Blenderのヘッドレス実行（`blender --background sonar_radar10.blend --python blender_export.py`）でSTL再生成・動作確認済み。
- `sonar_radar.xml`のmesh asset名・geom名を追従（`radar_base_red_mesh`/`base_red_geom` → `radar_base_left_mesh`/`base_left_geom`、blue側も同様）。rgba値（色）自体は変更なし。
- 2026-08-11のマイルストーン7（development_log.md）で合意した「別途まとまった作業として行う」TODOの実施。

### v0.10.2（2026-07-06）

**フォースセンサーのストローク実測値への修正**

- ボタン突出量・ストロークを実測 8mm に修正（旧: 9.5mm）。
- `force_sensor_button.stl` を 8mm 突出量で再エクスポート。
- `button_slide` range 0〜0.008m、stiffness 1250 N/m（10N÷0.008m）に更新。
- `force_site` をボタン本体（可動）からセンサー本体ハウジング（固定）の Z=0.030m に移動。
  ストロークの 62% 押込み位置 = Hard-pressed 判定点。
- `press_block` pos Z を 0.0411 → 0.0405m に修正（ボタン位置変更に追従）。
- equality `solref="0.002 1"` でタイト拘束（重力残差 0.05mm 以下）。
- `libspikehat_sim` サブモジュールを b3591f1 に更新。

### v0.10.1（2026-07-05）

**ドキュメント画像を更新**

- `docs/sonar_radar_overview.png` を追加（`.jpg` から `.png` に変更）。
- `docs/sonar_radar_sim_snap.png` を更新（starter/フォースセンサーを含む最新外観）。
- `README.md` / `README_ja.md` の画像参照を `.jpg` から `.png` に変更。

### v0.10.0（2026-07-04）

**全センサーを libspikehat_sim の include コンポーネントに移行**

- 距離センサー・カラーセンサー・フォースセンサーの3つすべてを
  `libspikehat_sim/examples/components/` の `<include>` として組み込む方式に統一。
  各センサーの geom・joint・site は `sonar_radar.xml` のインライン定義から分離された。
- `blender_export.py` に `starter`（フォースセンサーユニット）の
  `sensor_mount` pos を自動計算するセクションを追加。
- カラーセンサーの `SENSOR_HOME_OFFSET` 符号修正（+5° → −5°）、
  `euler="-90 -185 0"` に更新。
- `button.stl` を `force_sensor_button.stl` にリネーム。
- `libspikehat_sim` の `force_sensor.io` の原点を
  センサー本体底面中心（LDraw 原点）に合わせた
  （`shared_offset=(0,0,0)` を確認済み）。
- `sonar_radar09.blend` を最新の Studio モデルから再生成。

### v0.9.0（2026-06-29）

**Hakoniwa asset 化・libspikehat_pdu 作成・結合テスト完了**

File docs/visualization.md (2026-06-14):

# スキャン結果の可視化手順

実機・SIMのスキャン結果を取得し、`raspi/sonar_plot.py` で可視化するまでの手順。
`docs/scan_real.json`/`docs/scan_real_example.png`、
`docs/scan_sim.json`/`docs/scan_sim_example.png` はこの手順で作成した例。

## 1. 実機データの取得

Raspberry Pi上で `raspi/run.sh` を実行し、標準出力のJSONをファイルに保存する。

```bash
cd ~/projects/sonar_radar/raspi
bash run.sh > scan_real.json
```

フォースセンサー（終了スイッチ）を押すとスキャンが終了し、JSONが出力される。
作成した `scan_real.json` を、Mac側のリポジトリの `docs/` にコピーする（`scp` 等）。

## 2. SIMデータの取得

### 2.1 注意点：バッチ実行はスキャンが終了しない

`sim/sonar_radar_sim.py` をビューアなし（`python3`）で実行すると、
フォースセンサー（`press_body`）を押す手段がないため、`do_continuous_scan` の
終了条件が満たされず、標準出力にJSONが出力されない（プロセスを止めるまで動き続ける）。

### 2.2 手順：標準エラーのログから再構成する

実用上は、標準エラー出力（`[ xx.xxs] motor:... dome:... -> ...`形式のログ）を
タイムアウト等で適当な時間だけ取得し、そこから `{"angle":..., "dome_angle":...,
"distance_mm":...}` のJSON配列を再構成すれば `sonar_plot.py` にそのまま使える。

```bash
cd sim
timeout 45 python3 sonar_radar_sim.py > /dev/null 2>sim_scan.log
```

```python
# sim_scan.log -> scan_sim.json
import re, json

results = []
pat = re.compile(r"motor:\s*([+-]?\d+)°\s*dome:\s*([+-]?\d+\.\d+)°\s*->\s*(null|\d+)\s*(?:mm)?")
for line in open("sim_scan.log"):
    m = pat.search(line)
    if not m:
        continue
    angle = int(m.group(1))
    dome = float(m.group(2))
    dist = None if m.group(3) == "null" else int(m.group(3))
    results.append({"angle": angle, "dome_angle": dome, "distance_mm": dist})

json.dump(results, open("scan_sim.json", "w"))
```

> ビューア（`mjpython sonar_radar_sim.py --viewer`）を使い、Controlタブの
> `press_ctrl` を操作してスキャンを正規に終了させれば、標準出力のJSONを
> そのまま使うこともできる。

## 3. 可視化

```bash
python3 raspi/sonar_plot.py docs/scan_real.json -o docs/scan_real_example.png --title "実機スキャン結果"
python3 raspi/sonar_plot.py docs/scan_sim.json  -o docs/scan_sim_example.png  --title "SIMスキャン結果"
```

`sonar_plot.py` は `matplotlib`/`numpy` に依存する（`pip install matplotlib`）。
日本語フォントは `Noto Sans CJK JP`（Linux）/ `Hiragino Sans`（macOS）/
`IPAGothic` のいずれかが必要。

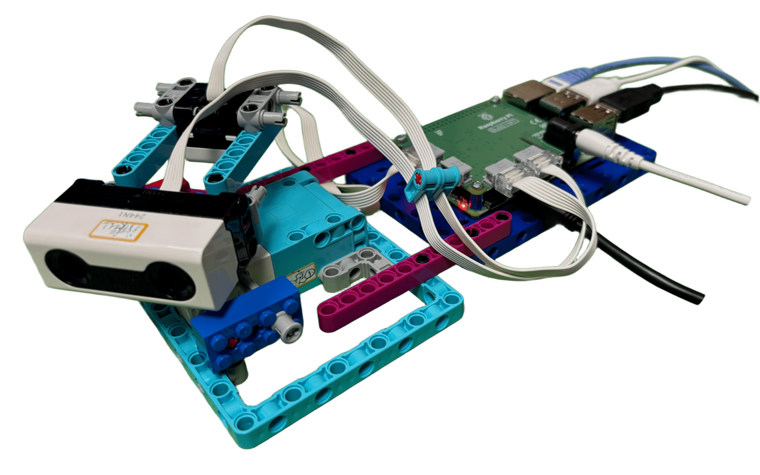
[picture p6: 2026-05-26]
docs/sonar_radar_overview.jpg

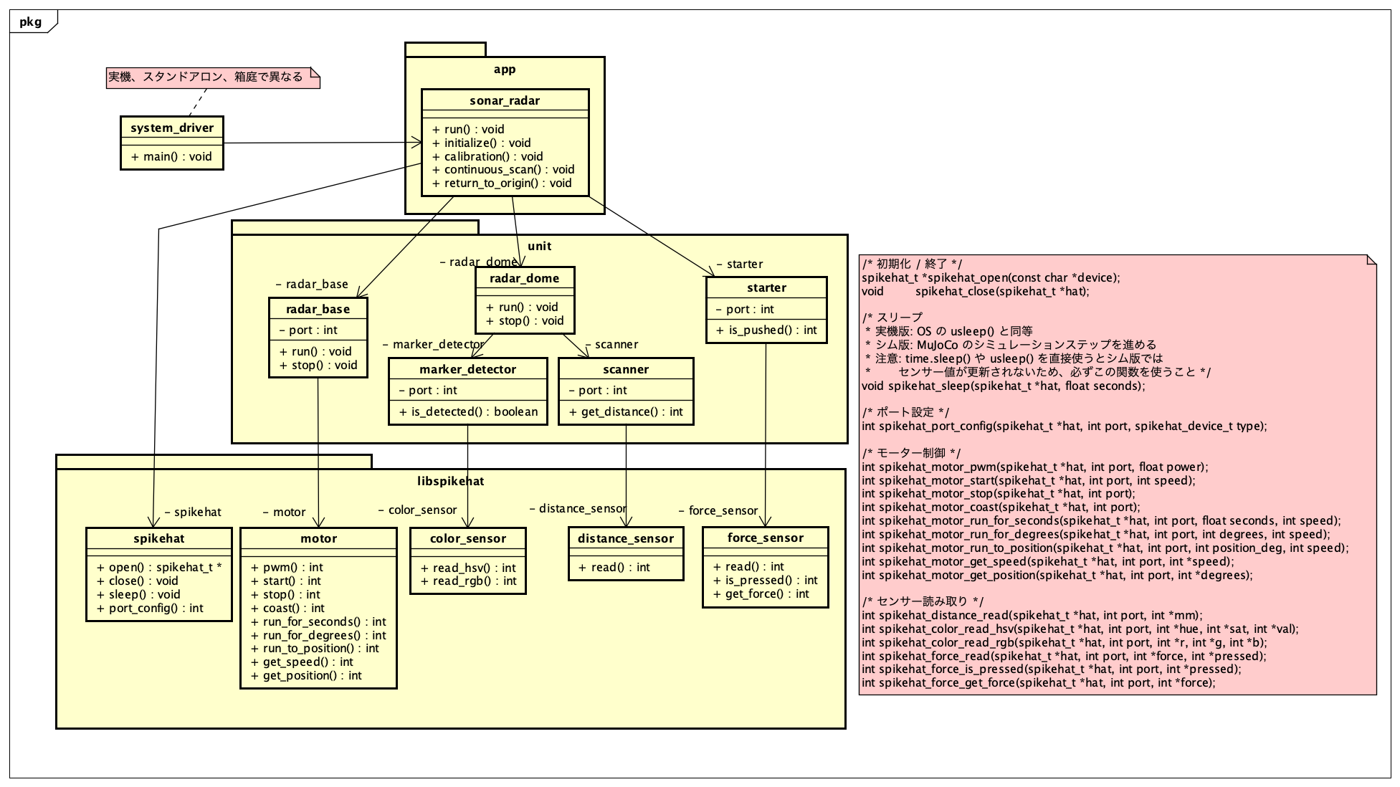
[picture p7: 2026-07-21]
asta/sonar_radarのクラス図.png

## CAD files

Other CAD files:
mujoco_model/meshes/radar_base_panel.stl
mujoco_model/meshes/radar_dome.stl
mujoco_model/meshes/radar_base_left.stl
mujoco_model/meshes/bevel_gear_12.stl
mujoco_model/meshes/bevel_gear_36.stl
mujoco_model/meshes/radar_base_gray.stl
mujoco_model/meshes/radar_base_right.stl
mujoco_model/meshes/obstacle_wall_a.stl
mujoco_model/meshes/obstacle_wall_b.stl
mujoco_model/meshes/sonar_sensor.stl
mujoco_model/meshes/color_sensor.stl
mujoco_model/meshes/press_block.stl
mujoco_model/meshes/force_sensor_body.stl
mujoco_model/meshes/distance_sensor.stl
mujoco_model/meshes/force_sensor_button.stl
mujoco_model/blender/sonar_radar08.blend
mujoco_model/blender/sonar_radar09.blend
mujoco_model/blender/sonar_radar10.blend

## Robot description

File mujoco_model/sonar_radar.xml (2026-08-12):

<mujoco model="sonar_radar">

  <compiler angle="degree" meshdir="meshes/"/>

  <option timestep="0.001" gravity="0 0 -9.81"/>

  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

  <worldbody>

    <light name="light_top" pos="0 0 1.5" dir="0 0 -1" diffuse="0.8 0.8 0.8" specular="0.2 0.2 0.2" directional="true"/>
    <light name="light_fill" pos="1 -1 0.8" dir="-1 1 -0.8" diffuse="0.4 0.4 0.4" specular="0.0 0.0 0.0" directional="true"/>

    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
    <body name="wall_body_a" pos="0.0080 -0.0380 0.0000">
      <joint name="wall_a_x" type="slide" axis="1 0 0" range="-0.08 0.08" damping="5.0"/>
      <joint name="wall_a_y" type="slide" axis="0 1 0" range="-0.080 0.20" damping="5.0"/>
      <inertial pos="0 0 0" mass="0.05" diaginertia="0.0001 0.0001 0.0001"/>
      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
    </body>

    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
    <body name="wall_body_b" pos="-0.0480 -0.0796 0.0000">
      <joint name="wall_b_x" type="slide" axis="1 0 0" range="-0.08 0.136" damping="5.0"/>
      <joint name="wall_b_y" type="slide" axis="0 1 0" range="-0.040 0.25" damping="5.0"/>
      <inertial pos="0 0 0" mass="0.05" diaginertia="0.0001 0.0001 0.0001"/>
      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
    </body>

    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
    <body name="radar_base" pos="0 0 0" euler="0 0 0">
      <inertial pos="0 0 0" mass="1.0" diaginertia="0.01 0.01 0.01"/>
      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
      <body name="motor_rotor" pos="0.0078 0.0482 0.0237" euler="0 0 0">
        <inertial pos="0 0 0" mass="0.05" diaginertia="0.0005 0.0005 0.0005"/>
        <joint name="motor_joint" type="hinge" axis="0 0 -1" damping="0.85" armature="0.001"/>
        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
      </body>

      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
      <body name="bevel_gear_36" pos="0.0076 0.0728 0.0300" euler="0 0 0">
        <inertial pos="0 0 0" mass="0.05" diaginertia="0.0005 0.0005 0.0005"/>
        <joint name="dome_joint" type="hinge" axis="0 0 1" damping="0.1" armature="0.0005"/>
        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
        <body name="radar_dome" pos="0 0 0" euler="0 0 0">
          <inertial pos="0 0 0" mass="0.1" diaginertia="0.001 0.001 0.001"/>
          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
          <body name="sonar_sensor" pos="0.0010 -0.0093 0.0227" euler="0 0 -175">
            <include file="../sim/libspikehat_sim/examples/components/distance_sensor_body.xml"/>
          </body>
          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
          <body name="color_sensor" pos="-0.0032 0.0393 0.0387" euler="-90 -185 0">
            <include file="../sim/libspikehat_sim/examples/components/color_sensor_body.xml"/>
          </body>
        </body>

      </body>

    </body>

    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
    <body name="sensor_mount" pos="0.0722 0.1037 0.0160" euler="0 0 90">
      <include file="../sim/libspikehat_sim/examples/components/force_sensor_body.xml"/>
    </body>

    <body name="press_block" pos="0.072 0.104 0.057" euler="0 0 0">
      <joint name="press_slide" type="slide" axis="0 0 -1" range="0 0.008" damping="5"/>
      <inertial pos="0 0 0.014" mass="0.020" diaginertia="0.0001 0.0001 0.0001"/>
      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
    </body>

  </worldbody>

  <equality>
    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
    <joint joint1="dome_joint" joint2="motor_joint" polycoef="0 0.33333333 0 0 0"/>
    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
    <joint joint1="press_slide" joint2="button_slide" polycoef="0 1 0 0 0" solref="0.002 1"/>
  </equality>

  <actuator>
    <motor name="turret_motor" joint="motor_joint" gear="10" ctrllimited="true" ctrlrange="-1 1"/>
    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
    <motor name="press_ctrl" joint="button_slide" gear="1" ctrllimited="true" ctrlrange="0 10"/>
    <position name="wall_a_x_ctrl" joint="wall_a_x" kp="50" ctrllimited="true" ctrlrange="-0.08 0.08"/>
    <position name="wall_a_y_ctrl" joint="wall_a_y" kp="50" ctrllimited="true" ctrlrange="-0.080 0.20"/>
    <position name="wall_b_x_ctrl" joint="wall_b_x" kp="50" ctrllimited="true" ctrlrange="-0.08 0.136"/>
    <position name="wall_b_y_ctrl" joint="wall_b_y" kp="50" ctrllimited="true" ctrlrange="-0.040 0.25"/>
  </actuator>

  <sensor>
    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
    <jointpos name="turret_angle" joint="motor_joint"/>
    <jointvel name="turret_vel" joint="motor_joint"/>
    <jointpos name="dome_angle" joint="dome_joint"/>
    <jointvel name="dome_vel" joint="dome_joint"/>
    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
    <framepos name="distance_pos" objtype="site" objname="distance_site"/>
    <framequat name="distance_quat" objtype="site" objname="distance_site"/>
    <framepos name="color_pos" objtype="site" objname="color_site"/>
    <framequat name="color_quat" objtype="site" objname="color_site"/>
    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
    <touch name="force_touch" site="force_site"/>
  </sensor>

</mujoco>

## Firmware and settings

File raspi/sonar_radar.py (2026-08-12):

#!/usr/bin/env python3
"""
sonar_radar.py - レーダースキャナー（ステートマシン版）

SonarRadarSM クラスが1ティックだけ処理してすぐリターンする「開いたループ」を実装する。
外側ループ（system_driver）が tick() を繰り返し呼び、hat.sleep() で時間を進める。

  実機:      time.sleep() で進める → main() が担う
  Hakoniwa: hakopy.usleep() で進める → sonar_radar_ctrl_hako.py が担う
  sim:       hat.sleep() で MuJoCo ステップを進める → sonar_radar_sim.py が担う

ステートマシン状態:
  INIT → CALIBRATING → WAIT_FOR_START → SCANNING → WAIT_FOR_STOP → TERMINATED

ハードウェア構成:
  ポートA(0): Lアンギュラーモーター  - ドーム旋回（ギア減速 1:3、回転方向反転）
  ポートB(1): フォースセンサー       - スタート/ストップトリガー
  ポートC(2): カラーセンサー         - 旋回端マーカー検出（緑=左限界検出, 青=右限界検出。
                                      緑マーカー自体は物理的には右側に設置されているが、
                                      検出時にドームが向いているのは左限界のため「緑=左」
                                      と呼ぶ。旧・赤マーカー、実機実測(2026-08-11)で
                                      チャタリング・誤検出が判明し緑に変更）
  ポートD(3): 距離センサー           - 障害物計測
"""

import sys
import json
import time
import enum

# --- 実機専用設定 ---
try:
    from spikehat import SpikeHat, DEVICE_MOTOR_L, DEVICE_FORCE, DEVICE_COLOR, DEVICE_DISTANCE
except ImportError:
    import os
    sys.path.insert(0, os.path.join(os.path.dirname(__file__), 'libspikehat', 'python'))
    from spikehat import SpikeHat, DEVICE_MOTOR_L, DEVICE_FORCE, DEVICE_COLOR, DEVICE_DISTANCE

# --- ハードウェア設定 ---
PORT_MOTOR    = 0
PORT_FORCE    = 1
PORT_COLOR    = 2
PORT_DISTANCE = 3

# --- 距離設定 ---
DIST_MIN_MM    = 50
DIST_MAX_MM    = 300
DIST_INVALID   = 2000
DIST_OFFSET_MM = 25

# --- モーター設定 ---
SCAN_PWM          = 0.1
ALIGN_SPEED       = 10
SAMPLE_INTERVAL_S = 0.05

# --- ギア比 ---
GEAR_RATIO         = 3
SENSOR_HOME_OFFSET = 5

# フォースセンサー: 有効押下の最低ティック数（MIN_PRESS = 0.1s / SAMPLE_INTERVAL_S）
MIN_PRESS_TICKS = 2


def dome_to_motor(dome_deg):
    return -dome_deg * GEAR_RATIO


def motor_to_dome(motor_deg):
    return -motor_deg / GEAR_RATIO


# --- カラー判定 ---
# 実機実測(2026-08-11)に基づくしきい値。赤は色相0/360度の境界に近く、
# センサーノイズでhueが339〜342付近を行き来しチャタリングが起きたこと、
# 加えて赤のしきい値は彩度・明度の条件が緩く機体周辺の茶色パーツ
# (hue=348〜353)を誤検出するリスクがあったことが実測で確認され、緑に
# 変更した(sonar_radar-zenoh-bridge/bridge/real_marker_detector.pyと同じ値)。
GREEN_HUE_LO = 145
GREEN_HUE_HI = 185
GREEN_SAT_MIN = 150
GREEN_VAL_MIN = 50
BLUE_HUE_LO  = 210
BLUE_HUE_HI  = 270
BLUE_SAT_MIN = 580
BLUE_VAL_MIN = 100


def is_green(hue, sat, val):
    if sat < GREEN_SAT_MIN or val < GREEN_VAL_MIN:
        return False
    return GREEN_HUE_LO <= hue <= GREEN_HUE_HI


def is_blue(hue, sat, val):
    if sat < BLUE_SAT_MIN or val < BLUE_VAL_MIN:
        return False
    return BLUE_HUE_LO <= hue <= BLUE_HUE_HI


def filter_distance(mm):
    if mm == DIST_INVALID:
        return None
    corrected = mm + DIST_OFFSET_MM
    if corrected < DIST_MIN_MM or corrected > DIST_MAX_MM:
        return None
    return corrected


# ─── ステートマシン ────────────────────────────────────────────────────────────

class State(enum.Enum):
    INIT              = 'INIT'
    CALIB_TO_ZERO     = 'CALIB_TO_ZERO'     # 待つもの: モーターが機械的0位置に到達
    CALIB_TO_OFFSET   = 'CALIB_TO_OFFSET'   # 待つもの: モーターがSENSOR_HOME_OFFSET位置に到達
    WAIT_FOR_START    = 'WAIT_FOR_START'    # 待つもの: フォースセンサーの押下→解放
    SCANNING          = 'SCANNING'          # 待つもの: フォースセンサーの押下→解放
    RETURN_TO_ORIGIN  = 'RETURN_TO_ORIGIN'  # 待つもの: モーターがzero_posに到達
    TERMINATED        = 'TERMINATED'


class SonarRadarSM:
    """
    sonar_radar のステートマシン（フラット1段）。
    tick(hat) を呼ぶたびに1ステップ処理してすぐリターンする。
    外側ループが hat.sleep() で時間を進める責任を持つ。

    clock: 経過時間（秒）を返す callable。省略時は time.monotonic。
           Hakoniwa では lambda: hat._sim_time_usec / 1e6 を渡す。
    """

    def __init__(self, clock=None):
        self._clock       = clock if clock is not None else time.monotonic
        self.state        = State.INIT
        self.results      = []
        self._zero_pos    = 0
        self._force_on    = False  # クリック検出用（共通）
        self._press_ticks = 0      # クリック検出用（共通）
        self._scan_pwm    = SCAN_PWM
        self._on_marker   = False

    def tick(self, hat):
        if   self.state == State.INIT:             self._tick_init(hat)
        elif self.state == State.CALIB_TO_ZERO:    self._tick_calib_to_zero(hat)
        elif self.state == State.CALIB_TO_OFFSET:  self._tick_calib_to_offset(hat)
        elif self.state == State.WAIT_FOR_START:   self._tick_wait_for_start(hat)
        elif self.state == State.SCANNING:         self._tick_scanning(hat)
        elif self.state == State.RETURN_TO_ORIGIN: self._tick_return_to_origin(hat)

    def is_terminated(self):
        return self.state == State.TERMINATED

    # ── INIT ──────────────────────────────────────────────────────────────────

    def _tick_init(self, hat):
        hat.port_config(PORT_MOTOR,    DEVICE_MOTOR_L)
        hat.port_config(PORT_FORCE,    DEVICE_FORCE)
        hat.port_config(PORT_COLOR,    DEVICE_COLOR)
        hat.port_config(PORT_DISTANCE, DEVICE_DISTANCE)
        print(f"[{self._clock():6.2f}s] キャリブレーション: 機械的0位置へ移動...", file=sys.stderr)
        self.state = State.CALIB_TO_ZERO

    # ── CALIB_TO_ZERO ─────────────────────────────────────────────────────────
    # 待つもの: モーターが機械的0位置（encoder=0）に到達

    def _tick_calib_to_zero(self, hat):
        if self._drive_to(hat, 0, ALIGN_SPEED):
            offset = round(dome_to_motor(SENSOR_HOME_OFFSET))
            print(f"[{self._clock():6.2f}s] SENSOR_HOME_OFFSET(dome {SENSOR_HOME_OFFSET}度 = motor {offset}度)分を補正...",
                  file=sys.stderr)
            self.state = State.CALIB_TO_OFFSET

    # ── CALIB_TO_OFFSET ───────────────────────────────────────────────────────
    # 待つもの: モーターがSENSOR_HOME_OFFSET位置に到達 → zero_pos を記録

    def _tick_calib_to_offset(self, hat):
        offset = round(dome_to_motor(SENSOR_HOME_OFFSET))
        if self._drive_to(hat, offset, ALIGN_SPEED):
            self._zero_pos    = hat.motor_get_position(PORT_MOTOR)
            self._force_on    = False
            self._press_ticks = 0
            print(f"[{self._clock():6.2f}s] キャリブレーション完了 (現在位置 = 0°, encoder={self._zero_pos})",
                  file=sys.stderr)
            print(f"[{self._clock():6.2f}s] フォースセンサーを押して離すとスキャン開始します...", file=sys.stderr)
            self.state = State.WAIT_FOR_START

    # ── WAIT_FOR_START ────────────────────────────────────────────────────────
    # 待つもの: フォースセンサーのクリック（押下→解放）

    def _tick_wait_for_start(self, hat):
        if self._detect_force_click(hat):
            print(f"[{self._clock():6.2f}s] スキャン開始", file=sys.stderr)
            self._scan_pwm  = SCAN_PWM
            self._on_marker = False
            hat.motor_pwm(PORT_MOTOR, self._scan_pwm)
            print(f"連続スキャン開始: 速度(PWM)={self._scan_pwm}, "
                  f"間隔={SAMPLE_INTERVAL_S*1000:.0f}ms", file=sys.stderr)
            self.state = State.SCANNING

    # ── SCANNING ──────────────────────────────────────────────────────────────
    # 待つもの: フォースセンサーの押下→解放

    def _tick_scanning(self, hat):
        # マーカー検出
        try:
            h, s, v = hat.color_read_hsv(PORT_COLOR)
            marker = is_green(h, s, v) or is_blue(h, s, v)
            if marker and not self._on_marker:
                name = "緑" if is_green(h, s, v) else "青"
                print(f"{name}マーカー検出: 反転します", file=sys.stderr)
                self._scan_pwm = -self._scan_pwm
                hat.motor_pwm(PORT_MOTOR, self._scan_pwm)
            self._on_marker = marker
        except RuntimeError:
            pass

        # 角度・距離を記録
        try:
            angle      = hat.motor_get_position(PORT_MOTOR) - self._zero_pos
            dome_angle = motor_to_dome(angle)
        except RuntimeError:
            angle = dome_angle = None

        try:
            dist = filter_distance(hat.distance_read(PORT_DISTANCE))
        except RuntimeError:
            dist = None

        self.results.append({"angle": angle, "dome_angle": dome_angle, "distance_mm": dist})

        label     = f"{dist:5d} mm" if dist is not None else "  null"
        angle_str = f"{angle:+4d}" if angle is not None else "  --"
        dome_str  = f"{dome_angle:+6.1f}" if dome_angle is not None else "    --"
        print(f"[{self._clock():6.2f}s] motor:{angle_str}° dome:{dome_str}° -> {label}",
              file=sys.stderr)

        # フォースセンサーのクリックでスキャン終了
        if self._detect_force_click(hat):
            print(f"[{self._clock():6.2f}s] フォースセンサー: スキャン終了", file=sys.stderr)
            hat.motor_stop(PORT_MOTOR)
            print(f"[{self._clock():6.2f}s] 0位置へ復帰: zero_pos={self._zero_pos}", file=sys.stderr)
            self.state = State.RETURN_TO_ORIGIN

    # ── RETURN_TO_ORIGIN ──────────────────────────────────────────────────────
    # 待つもの: モーターがzero_posに到達

    def _tick_return_to_origin(self, hat):
        if self._drive_to(hat, self._zero_pos, ALIGN_SPEED):
            print(f"[{self._clock():6.2f}s] 0位置へ復帰完了", file=sys.stderr)
            self.state = State.TERMINATED

    # ── 内部ヘルパー ──────────────────────────────────────────────────────────

    def _detect_force_click(self, hat) -> bool:
        """フォースセンサーのクリック（押下→解放）を検出する。毎ティック呼ぶこと。
        MIN_PRESS_TICKS 以上の押下の後に解放されたとき True を返す。"""
        try:
            pressed = hat.force_is_pressed(PORT_FORCE)
        except RuntimeError:
            return False
        if pressed and not self._force_on:
            self._force_on    = True
            self._press_ticks = 1
        elif pressed and self._force_on:
            self._press_ticks += 1
        elif not pressed and self._force_on:
            self._force_on = False
            if self._press_ticks >= MIN_PRESS_TICKS:
                self._press_ticks = 0
                return True
            self._press_ticks = 0
        return False

    def _drive_to(self, hat, target: int, speed: int) -> bool:
        """目標角度に向けて1ティック分トルクを適用する。到達したら True を返す。"""
        try:
            current = hat.motor_get_position(PORT_MOTOR)
        except RuntimeError:
            return False
        err = target - current
        if abs(err) < 3:
            hat.motor_stop(PORT_MOTOR)
            return True
        pwm = (abs(speed) / 100.0) * 0.3
        hat.motor_pwm(PORT_MOTOR, pwm if err > 0 else -pwm)
        return False


# ─── 実機用エントリポイント ────────────────────────────────────────────────────

def main():
    t_process_start = time.monotonic()
    try:
        hat_instance = SpikeHat()
    except RuntimeError:
        print("エラー: Build HAT ファームウェアがロードされていません。", file=sys.stderr)
        sys.exit(1)
    print(f"[SpikeHat()構築: {time.monotonic() - t_process_start:.2f}s]", file=sys.stderr)

    start_time = time.monotonic()

    with hat_instance as hat:
        hat.sleep(1.0)
        sm = SonarRadarSM(clock=lambda: time.monotonic() - start_time)
        while not sm.is_terminated():
            sm.tick(hat)
            hat.sleep(SAMPLE_INTERVAL_S)

    print(json.dumps(sm.results, ensure_ascii=False, indent=2))


if __name__ == "__main__":
    main()

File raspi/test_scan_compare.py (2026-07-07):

#!/usr/bin/env python3
"""
test_scan_compare.py - 実機/シミュレーター共通スキャン比較テスト

実機（Raspberry Pi）とシミュレーター（Hakoniwa PDU）で同一ロジックを実行し、
カラーセンサーの赤・青・その他の検出数を比較するためのデータを収集する。

動作:
  1. モーターを PWM で旋回開始
  2. カラーセンサーで赤・青マーカーを検出するたびに旋回方向を反転
  3. MAX_REVERSALS 回反転したらスキャン終了
  4. 結果を JSON で標準出力（実機）またはファイルに出力

使用方法:
  実機（Raspberry Pi）:
    python3 test_scan_compare.py [出力ファイル.json]

  シミュレーター（Hakoniwa）:
    bash run-hakopy.bash examples/spikehat/test_scan_compare.py [出力ファイル.json]
"""

import sys
import json
import time

# --- 定数 ---
PORT_MOTOR    = 0
PORT_FORCE    = 1
PORT_COLOR    = 2
PORT_DISTANCE = 3

SCAN_PWM        = 0.15   # 旋回速度
MAX_REVERSALS   = 6      # この回数反転したら終了（赤3往復+青3往復程度）
SAMPLE_INTERVAL = 0.1    # サンプリング間隔（秒）
DIST_INVALID    = 2000
DIST_OFFSET_MM  = 25

# HSV 判定閾値
# 注意: 実機（SPIKE Prime）は内蔵 LED で照らすため V が高くなる。
#       シムの geom rgba は視覚的な暗さ（青 V≈51）のため BLUE_VAL_MIN を低く設定する。
#       この差は実機/シム間の校正差として記録する。
RED_SAT_MIN  = 40
RED_VAL_MIN  = 40
BLUE_HUE_LO  = 210
BLUE_HUE_HI  = 270
BLUE_SAT_MIN = 40    # 実機相当: 58（sonar_radar.py の 580 を 0-100 スケールに換算）
BLUE_VAL_MIN = 30    # 実機相当: 100。シムの青 geom V≈51 に合わせて緩和


def rgb_to_hsv(r, g, b):
    """RGB (0-255) → HSV (H:0-360, S:0-100, V:0-100)"""
    r_, g_, b_ = r / 255.0, g / 255.0, b / 255.0
    cmax = max(r_, g_, b_)
    cmin = min(r_, g_, b_)
    diff = cmax - cmin

    if diff == 0:
        h = 0
    elif cmax == r_:
        h = int(60 * ((g_ - b_) / diff) % 360)
    elif cmax == g_:
        h = int(60 * ((b_ - r_) / diff) + 120)
    else:
        h = int(60 * ((r_ - g_) / diff) + 240)
    if h < 0:
        h += 360

    s = 0 if cmax == 0 else int((diff / cmax) * 100)
    v = int(cmax * 100)
    return h, s, v


def is_red(h, s, v):
    if s < RED_SAT_MIN or v < RED_VAL_MIN:
        return False
    return h >= 340 or h <= 20


def is_blue(h, s, v):
    if s < BLUE_SAT_MIN or v < BLUE_VAL_MIN:
        return False
    return BLUE_HUE_LO <= h <= BLUE_HUE_HI


def classify(r, g, b):
    """RGB → 'red' / 'blue' / 'floor' / 'none'"""
    if r == 0 and g == 0 and b == 0:
        return 'none'
    h, s, v = rgb_to_hsv(r, g, b)
    if is_red(h, s, v):
        return 'red'
    if is_blue(h, s, v):
        return 'blue'
    return 'floor'


def do_scan(hat):
    """スキャン実行。サンプルリストを返す。"""
    samples   = []
    pwm       = SCAN_PWM
    reversals = 0
    on_marker = False

    hat.motor_pwm(PORT_MOTOR, pwm)
    print(f"スキャン開始 (PWM={pwm}, 最大反転={MAX_REVERSALS}回)", file=sys.stderr)

    while reversals < MAX_REVERSALS:
        # カラー読取・分類
        try:
            r, g, b = hat.color_read_rgb(PORT_COLOR)
        except RuntimeError:
            r, g, b = 0, 0, 0

        label = classify(r, g, b)
        marker = (label == 'red' or label == 'blue')

        # マーカー検出エッジで反転
        if marker and not on_marker:
            pwm = -pwm
            hat.motor_pwm(PORT_MOTOR, pwm)
            reversals += 1
            print(f"  [{label}] 反転 {reversals}/{MAX_REVERSALS}", file=sys.stderr)
        on_marker = marker

        # 距離読取
        try:
            mm = hat.distance_read(PORT_DISTANCE)
            if mm == DIST_INVALID:
                mm = None
            elif mm is not None:
                mm = mm + DIST_OFFSET_MM
        except RuntimeError:
            mm = None

        samples.append({
            "step":        len(samples),
            "r": r, "g": g, "b": b,
            "label":       label,
            "distance_mm": mm,
        })

        hat.sleep(SAMPLE_INTERVAL)

    hat.motor_stop(PORT_MOTOR)
    hat.sleep(0.3)
    print(f"スキャン完了: {len(samples)} サンプル", file=sys.stderr)
    return samples


def make_summary(samples):
    counts = {"red": 0, "blue": 0, "floor": 0, "none": 0}
    for s in samples:
        counts[s["label"]] += 1
    dists = [s["distance_mm"] for s in samples if s["distance_mm"] is not None]
    return {
        "total_samples": len(samples),
        "red_hits":      counts["red"],
        "blue_hits":     counts["blue"],
        "floor_hits":    counts["floor"],
        "no_hit":        counts["none"],
        "dist_valid":    len(dists),
        "dist_min_mm":   min(dists) if dists else None,
        "dist_max_mm":   max(dists) if dists else None,
    }


# ─── 実機モード ────────────────────────────────────────────────────────────

def run_real(output_path):
    try:
        from spikehat import SpikeHat, DEVICE_MOTOR_L, DEVICE_COLOR, DEVICE_DISTANCE
    except ImportError:
        import os
        sys.path.insert(0, os.path.join(os.path.dirname(__file__), 'libspikehat', 'python'))
        from spikehat import SpikeHat, DEVICE_MOTOR_L, DEVICE_COLOR, DEVICE_DISTANCE

    with SpikeHat() as hat:
        hat.port_config(PORT_MOTOR,    DEVICE_MOTOR_L)
        hat.port_config(PORT_COLOR,    DEVICE_COLOR)
        hat.port_config(PORT_DISTANCE, DEVICE_DISTANCE)
        hat.sleep(1.0)

        samples = do_scan(hat)

    result = {"summary": make_summary(samples), "samples": samples}
    out = json.dumps(result, ensure_ascii=False, indent=2)
    if output_path:
        with open(output_path, "w") as f:
            f.write(out)
        print(f"→ {output_path} に保存", file=sys.stderr)
    else:
        print(out)


# ─── Hakoniwa モード ───────────────────────────────────────────────────────
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

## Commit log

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2026-05-21 スキャン精度の改善と青マーカー検出の修正
    - 角度補正: 実際のエンコーダ値を使って累積誤差を解消
    - STOP_EARLY_DEG: コースト分を見込んでターゲット手前で停止
    - 速度調整: SCAN_SPEED=7, CALIB_SPEED=12 でオーバーシュートを低減
    - 青マーカー閾値: 実測値に基づき BLUE_HUE_LO=210, BLUE_SAT_MIN=580 に修正
    - 帰還: 命令値ではなく実際の位置から 0° へ戻るよう修正
    [sonar_radar.py]
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2026-05-26 README: スキャン仕様とプロジェクト構成を更新
    - ステップ角 5°→3°、有効距離 150-500mm→50-300mm に修正
    - docs/ と model/ ディレクトリをプロジェクト構成に追加
2026-05-26 LEGOモデルファイルを追加し、実機に合わせて修正
    model/sonar_radar04.io と .ldr を追加。
    不要な一時ファイルを削除。
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2026-05-26 センサーオフセット補正を追加
    旋回軸からセンサー面までの距離(DIST_OFFSET_MM=25mm)を定数化し、
    filter_distance()で補正後の値を旋回軸基準の距離として返すよう修正。
    DIST_MIN_MM/DIST_MAX_MMは旋回軸基準の有効距離として定義を統一した。
    [sonar_radar.py]
2026-06-09 Restructure repository layout
    - raspi/: Raspberry Pi code + libspikehat submodule
    - sim/: simulator code + libspikehat_sim submodule
    - studio_model/: Bricklink Studio models (04, 06)
    - mujoco_model/: MuJoCo model, meshes, blender scripts, documentation
    - docs/: scan results and overview images
    - Add .gitignore
    [motor_body.stl, motor_rotor.stl, radar_base_blue.stl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]
2026-06-10 Clean up studio_model and add sonar_radar06.blend
    - Remove sonar_radar04.io/ldr (superseded by 06)
    - Add sonar_radar06.blend to mujoco_model/blender/
    [sonar_radar06.blend]
2026-06-10 raspi/sonar_radar.py: use hat.sleep() and hat.motor_run_for_degrees()
    - Replace time.sleep() with hat.sleep() for sim compatibility
    - Remove custom motor_run_for_degrees() wrapper, use libspikehat API directly
    - Fix sys.path to use relative path to libspikehat submodule
    [sonar_radar.py]
2026-06-11 Update submodule libspikehat; tune gear=-10 for motor; update sonar_radar_sim.py for libspikehat_sim
    [sonar_radar.xml]
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2026-06-13 sonar_radar.xml からモーターメッシュ表示を削除し、STLをlibspikehat_simへ移動
    motor_body.stl/motor_rotor.stl は libspikehat_sim/examples/meshes に
    移動済み（座標系がsonar_radar07側と不整合のため一旦表示を外す）。
    body/joint構造（motor_body, motor_rotor, motor_joint, radar_dome）は維持。
    [motor_body.stl, motor_rotor.stl, sonar_radar.xml]
2026-06-13 sonar_radar07モデルを反映し、bevel_gear_12を含むメッシュを再エクスポート
    blender_export.py に bevel_gear_12 のエクスポート処理を追加し、
    radar_base_*/radar_dome を sonar_radar07.io ベースで再生成。
    sonar_radar07.io/.blend/.ldr とエクスポートログを追加。
    [bevel_gear_12.stl, radar_base_blue.stl, radar_base_gray.stl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]
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2026-06-13 MuJoCoモデルのギア連動構造を再構成し、センサーマーカー位置を調整
    motor_rotorをbevel_gear_12の旋回軸位置に再配置し、radar_domeを
    独立したbodyとしてdome_jointを持たせ、12T-36Tベベルギアの
    ギア比1:3・反転を表すequality制約を追加。dome_angle/dome_velの
    センサーも追加した。
    sonar_site/color_siteは実パーツ(37316c01.dat/37308c01.dat)の
    ドームローカル座標に基づき再配置し、ビューア確認で微調整した。
    [sonar_radar.xml]
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2026-06-13 radar_domeの旋回軸を36Tベベルギア中心に修正し、終了スイッチを追加
    旋回軸オブジェクトを距離センサー(37316c01.dat)から36Tベベルギア
    (32498.dat)に変更し、radar_dome.stlを再エクスポート。
    sonar_site/color_siteの位置をビューア確認に基づき再調整。
    turret_motorのgear符号を修正(-10→10)し、計算上のdome角度を
    実際の幾何と整合させた。
    sonar_radar02.pyのスキャン終了トリガー用にフォースセンサー
    (force_sensor_body/press_body)をworldbodyに追加。
    [bevel_gear_12.stl, radar_base_blue.stl, radar_base_gray.stl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]
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2026-06-13 sonar_radar_sim02.pyのビューア構成を実機と同じスレッド配置に修正
    sonar_radar02.py本体をメインスレッドでそのまま実行し、ビューアの
    表示更新を別スレッドに分離。これによりSpikeHatのsignalハンドラが
    通常通り動作し、signal.signalのモンキーパッチが不要になった。
    表示専用スレッドはmj_kinematics/mj_comPosのみを呼び、libspikehat_sim
    側のmj_stepと衝突しない。
    libspikehat_simをcd75aa7（sim_set_ctrl用mutex追加）に更新。
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2026-06-14 sonar_radarシミュレータに移動可能な壁を追加（位置調整は途中）
    mujoco_model/sonar_radar.xml:
    - 壁をwall_bodyとして可動化（wall_x/wall_yのslideジョイント+position
    アクチュエータ）
    - 壁サイズを実機相当（幅48mm×高さ120mm）に変更
    - 初期位置を実機の壁位置（旋回軸からX=+12mm, Y=+116mm）に合わせて配置
    sim/sonar_radar_sim02.py:
    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
    [sonar_radar.xml]
2026-06-14 sonar_radarシミュレータのdome初期姿勢・サンプリング間隔・表示を実機に合わせて調整
    - dome_jointの回転方向を実機に合わせて反転（赤マーカーを先に検出）
    - カラーセンサーの読み取り間隔を実機に合わせて0.2秒に変更
    - ビュアーの初期カメラをレーダー本体基準に拡大し、壁を半透明化
    - 壁の高さを実機に合わせて80mm(10ポッチ)に短縮
    [sonar_radar.xml]
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2026-06-14 sim: motor_jointのdampingを実機の旋回時間に合わせて調整、viewerデフォルトを実時間に修正
    - motor_joint damping 0.65 -> 0.85（赤-青マーカー間旋回時間を実機の約5秒に近づける）
    - sonar_radar_sim02.py の --speed デフォルトを 10 -> 1（実時間）に変更
    [sonar_radar.xml]
2026-06-14 02版を正式名に統合し、READMEとMuJoCoモデルドキュメントを更新
    - sonar_radar02.py/sonar_radar_sim02.py/sonar_plot02.pyを旧版に代わる正式名にリネーム
    - run.shをスクリプト位置基準の相対パスに修正
    - README/README_jaに実機・シミュレーションの使い分けとシミュレーション画面を追加
    - studio_to_mujoco.mdを現行モデル(sonar_radar07)構成に合わせて更新
    [sonar_radar.xml]
2026-06-14 実機/SIMのスキャン結果可視化をREADMEに追加し、FOV乖離を視覚的に記録
    - raspi/sonar_plot.pyのCJKフォント指定をmacOS/Linux双方で見つかるものに修正
    - docs/scan_real.json・docs/scan_sim.jsonと、それぞれのプロット例を追加
    - README/README_jaに「可視化」セクションを追加し、実機(超音波・広指向性)と
    SIM(単一レイキャスト)の検出範囲の違いを比較
    - 旧版の古い画像・スキャンデータ(scan02.json, scan_3deg.png等)を削除
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2026-06-15 fix: ビューア使用時のSpikeHat実体解放をビューアスレッド終了後に行う
    sonar_radar.py の with ブロック終了時にSpikeHat.close()が
    実体(mjModel/mjData/sim構造体)を解放すると、別スレッドの
    ビューアループがその後も同じポインタを参照してuse-after-free
    でクラッシュする。
    close()はビューアモード時はno-opとし、実体解放は
    _release_for_viewer()として明示し、_viewer_thread.join()後に
    呼び出すようにした。
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2026-06-16 feat: sonar_radar08対応 — bevel_gear_36分離・2壁・センサーsite位置確定
    主な変更:
    - studio_model: sonar_radar08.io/ldr を追加（LEGOモデル更新版）
    - blender_export.py: sonar_radar08対応（bevel_gear_36独立/ground_plate分離/
    STL面数上限対策/センサーsite位置をオブジェクト原点+定数オフセットで計算）
    - PLATE_H/STUD_PITCH 定数を定義
    - compute_local_site_pos に y_offset_m/z_offset_m パラメータを追加
    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
    [bevel_gear_12.stl, bevel_gear_36.stl, obstacle_wall_a.stl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]
2026-06-16 chore: Git LFS設定を追加し sonar_radar08.blend をコミット
    - .gitattributes: *.blend / *.stl を Git LFS 管理に設定
    - sonar_radar08.blend: sonar_radar08対応Blenderシーンを追加
    [sonar_radar08.blend]
2026-06-17 feat: 壁操作キーボード制御・移動範囲調整・衝突ガード追加
    - sim/sonar_radar_sim.py:
    - 壁を1スタッド単位でスナップ移動（_snap_stud）
    - キーボード操作: 1/2で壁選択、矢印キーで移動
    - WASDはMuJoCoビューアの組み込みショートカットと競合するため廃止
    - mujoco_model/sonar_radar.xml:
    - wall_a_y range: -0.05 → -0.080（ground_plateの端+1ポッチ）
    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
    [bevel_gear_12.stl, bevel_gear_36.stl, obstacle_wall_a.stl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]
2026-06-17 fix: モーター・ドームの回転方向を実機と一致させる
    motor_joint axis を "0 0 -1"（正=CW）に修正し、
    bevel gear equality polycoef を +1/3 に変更。
    viewer loop も +_motor_rad/3.0 に統一。
    正PWM→モーターCW→ドームCCW が実機と一致する。
    [sonar_radar.xml]
2026-06-17 docs: studio_to_mujoco.md を sonar_radar08 の変更内容に更新
    - サブモデル構造例を sonar_radar08 に更新（wall_a/b 追加）
    - motor/dome joint axis 設定と実機確認結果を6.3に記載
    - ガードジオム設計方針を6.4として追加
    - actuator一覧を wall_a/b の2壁構成に更新
    - キーボード壁操作の説明を8.1に追加
    - viewer loop の dome qpos 式を +/3.0 に修正
2026-06-18 uv環境対応: セットアップ手順更新とlibspikehat_simビルド修正
    - README_ja.md: uvによるvenv作成・libspikehat_simビルド手順を追記
    - uv.toml: python-preference=only-systemを設定（Homebrew Python優先）
    - .python-version: 3.12.3→3.12に変更（uv only-system対応）
    - sim/libspikehat_sim: CMakeLists.txt修正を含む最新コミットに更新
2026-06-18 libspikehat_sim サブモジュールを v0.6.0 に更新
    モーター回転方向を実機（SPIKE Prime）に合わせた修正を取り込む。
    正のspeed/power → 時計回り(CW) → position_deg増加（実機エンコーダと一致）
2026-06-18 sim: libspikehat_simをv0.7.0に更新
    C側符号反転を削除し、XMLのmotor_joint axis="0 0 -1"で
    方向を制御する方針に統一。色マーカー検出の赤青逆転を修正。
2026-06-23 model: センサーを独立bodyに分離、ドームのeuler補正を解消
    - blender_export.py:
    - radar_domeからsonar/colorセンサーを除外してエクスポート
    - sonar_sensor.stl / color_sensor.stlを独立生成
    - rotate_z_deg=180で座標変換を他パーツと統一（euler="0 0 180"不要）
    - sonar_sensorのみrotate_z_deg=180かつbody euler="0 0 180"でraycast方向を確保
    - OUTPUT_DIR/LOG_PATHを~/Projects配下に修正
    - sonar_radar.xml:
    - radar_dome euler="0 0 180" → "0 0 0"（二重補正を解消）
    - sonar_sensor / color_sensorを独立child bodyとして配置
    - site posをセンサーローカル座標で定義（調整が容易に）
    - me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
    [bevel_gear_12.stl, bevel_gear_36.stl, color_sensor.stl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]
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2026-06-30 sim: 距離センサーをlibspikehat_simコンポーネント(include)方式に移行
    - 距離センサー: distance_sensor_body.xml をinclude、pos="0.0010 -0.0093 0.0227"
    euler="0 0 -175"。位置はインライン版と同じ(gear36からの単純差分)、
    回転はドーム自体の5°傾きを保持したワールド回転ベースで算出。
    - libspikehat_sim submodule を更新(distance_sensorのSTUDIO標準姿勢化、
    center_mode="pivot_origin"化)
    - フォースセンサー機構(sensor_mount/press_block/button連動)を復元
    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
    [bevel_gear_12.stl, bevel_gear_36.stl, button.stl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]
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2026-07-02 sim: カラーセンサーをinclude方式に移行、サブモジュールをv0.9.6に更新
    - sonar_radar.xml: color_sensor を inline → <include> 方式に変更
    pos: gear36基準の単純差分（blender_export.py による算出値）
    euler: "90 5 180"（Rz(+5°)補正でドーム5°傾きに対応）
    - color_sensor.stl: 37308c01.dat から pivot_origin 方式で再生成
    - blender_export.py: compute_local_body_euler() を追加
    - sim/libspikehat_sim: v0.9.6 に更新（color_sensor_body.xml site pos修正）
    [color_sensor.stl, sonar_radar.xml, sonar_radar09.blend]
2026-07-02 docs: センサーinclude移行の検討資料をstudy/に保存
    distance_sensor/color_sensorのinclude方式移行で得た知見を記録。
    - MuJoCo includeのルートbody除去の挙動
    - pivot_origin STL規約
    - ドーム5°傾き補正の計算方法（intrinsic vs 親フレーム前置乗算）
    - インライン版とinclude版の比較検証モデル
    [test_distance_include_rotation.xml, test_old_vs_new_sensor.xml]
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2026-07-03 fix: MuJoCo pip パッケージと App のバージョン一致要件を明記、libspikehat_sim を v0.9.7 に更新
    pip mujoco と MuJoCo.app のバージョン不一致により mj_ray 内で mjModel ABI 非互換に
    よるクラッシュが発生していた問題の対処として、README にバージョン一致の注意を追記。
    libspikehat_sim サブモジュールを v0.9.7 (mj_ray geomgroup 非NULL化) に更新。
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2026-07-03 blender: sonar_radar09.blend を starter/radar_base 含む正版に差し戻す
    7bb98c1 でカラーセンサー対応時に上書きされ、starter・press_block・
    force_sensor 台座を含む radar_base が失われていた。
    42cf79d 時点のファイル（LFS キャッシュから復元）に差し戻す。
    [sonar_radar09.blend]
2026-07-03 blender: sonar_radar09.blend から STL を再エクスポート
    正版の sonar_radar09.blend（starter/press_block/force_sensor 台座含む
    radar_base）から全メッシュを再エクスポート。
    radar_base_*.stl に force_sensor 台座パーツ(48989.dat 等)が追加された。
    [bevel_gear_12.stl, bevel_gear_36.stl, color_sensor.stl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]
2026-07-03 mujoco_model: fix sensor orientations and rename button STL
    - color_sensor euler: fix SENSOR_HOME_OFFSET sign (was +5deg, now -5deg)
    → euler="-90 -185 0"
    - sensor_mount: auto-compute pos from blender_export.py (starter origin)
    pos="0.0722 0.1037 0.0160", euler="0 0 90"
    - Rename button.stl → force_sensor_button.stl; update sonar_radar.xml asset
    - blender_export.py: add starter pos/euler computation section,
    fix SENSOR_HOME_OFFSET sign, regenerate all STL meshes from sonar_radar09.blend
    [bevel_gear_12.stl, bevel_gear_36.stl, color_sensor.stl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]
2026-07-05 docs: update overview/sim images and switch to PNG format
    - Add docs/sonar_radar_overview.png (replaces .jpg)
    - Update docs/sonar_radar_sim_snap.png (includes starter/force sensor)
    - README.md/README_ja.md: update image reference from .jpg to .png
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2026-07-05 fix: update force_sensor stroke to 8mm and add include limitation docs
    - sonar_radar.xml: press_slide range 0.0095 → 0.008
    - studio_to_mujoco.md: add sec 10.4 on MuJoCo <include> limitation and
    weld equality workaround for force_sensor press_block attachment
    - libspikehat_sim submodule: bump to b3591f1 (8mm stroke fix)
    [sonar_radar.xml]
2026-07-05 sim: bump libspikehat_sim to b3591f1 (force_sensor 8mm stroke fix)
2026-07-05 docs: add v0.10.2 changelog for force_sensor 8mm stroke correction
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2026-07-06 raspi: replace hardcoded libspikehat path with submodule-relative path
    Use os.path.dirname(__file__) to locate raspi/libspikehat/python/
    so the code works on any user's environment without modification.
    [sonar_radar.py, test_stop_at_marker.py]
2026-07-07 WIP: Hakoniwa plant/controller integration (speed pacing pending)
    - sonar_radar_hako.py: plant asset, reads qpos[4] for motor_joint angle,
    uses sim_step() for real-time pacing (interim fix)
    - sonar_radar_ctrl_hako.py: controller asset, PduSpikeHat adapter with
    _time.sleep() (to be replaced by hakopy.usleep() per libspikehat_hako plan)
    - sonar_radar_viewer.py: separate mjpython viewer process via qpos file
    - test_scan_compare.py: comparison tool for raspi vs sim scan results
    Architecture decision: sonar_radar should become open-loop body;
    libspikehat_hako (Python, C-capable future) will replace PduSpikeHat
    with hakopy.usleep() for correct simulation-time-based sleep.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
    [test_scan_compare.py]
2026-07-07 WIP: implement libspikehat_hako with hakopy.usleep-based timing
    - libspikehat_hako.py: HakoSpikeHat extracted as independent library.
    sleep() uses hakopy.usleep() for simulation-time-based timing.
    motor_run_to_position() timeout uses sim_time counter, not wall clock.
    force_is_pressed() auto-press schedule also based on sim time.
    - sonar_radar_ctrl_hako.py: migrated from on_simulation_step to
    on_manual_timing_control. sonar_radar.py runs directly in the callback
    (no separate thread). time.monotonic() in sonar_radar.py is replaced
    with sim-time-based version before exec_module to fix MIN_PRESS_S check.
    - sonar_radar_hako.py: reverted to sim_step_no_pace() (pacing is now
    handled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
2026-07-07 fix: plant の force_sensor PDU を MuJoCo 物理状態から読むように修正
    常に False だった CH4 force_sensor PDU を hat.force_is_pressed() で
    MuJoCo のスターターボタン物理状態から取得して書くように修正する。
    これにより zenoh 経由でピア側へも正しい力センサー状態が伝達される。
2026-07-07 fix: --auto-start デフォルトを None に変更（物理ボタン操作をデフォルトに）
    引数なし起動時に auto-press が自動発火しないようにする。
    物理ボタンを使う場合はデフォルト動作、自動注入したい場合は
    --auto-start SEC --auto-stop SEC を明示する。
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2026-07-07 fix: Hakoniwa controller にリアル時刻同期を追加
    HakoSpikeHat.sleep() で hakopy.usleep() の後に time.sleep() を同時間
    呼び出すことで、シミュレーション時刻を壁時計に追従させる。
    conductor_start() にペーシング API がないため、コントローラー側で
    二重 sleep することでリアルタイム同期を実現する（開発者助言に基づく）。
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2026-07-27 Revert "feat: SonarRadarSMに他マシン連携用のイベントフックを追加"
    This reverts commit 038ed1553d007076a2cacee8a76fe6e6db496d42.
    [sonar_radar.py]
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2026-08-10 fix: Hakoniwa plant経由ビューアの表示設定とmjpython解決を修正
    - sonar_radar_viewer.pyにshow_left_ui=Falseとカメラ拡大設定(stat.center/extent)を追加。
    sonar_radar_sim.py側にのみ入っていた改善が引き継がれておらず、
    壁移動UIが操作しづらい状態になっていた。
    - sonar_radar_hako.pyのmjpython解決を、同一venv内を優先するよう堅牢化。
    PATH検索(shutil.which)がpyenv shimを誤って拾い、ビューア起動が
    クラッシュすることがあった。
    - README.md: 古い「Control tabで壁移動」の記述をキーボード操作の説明に更新。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
2026-08-11 fix: マーカー色を赤から緑に変更(チャタリング・誤検出対策)
    実機実測(2026-08-11)で、赤マーカーのしきい値(hue>=340)がセンサー
    ノイズによりチャタリングを起こすこと、さらに機体周辺の茶色パーツ
    (hue=348〜353)を「赤」として誤検出するリスクがあったことが判明した。
    黄色・緑を候補に実測した結果、周辺の既知色(水色・紫・青・茶色)から
    最も離れている緑(hue145〜185)を採用した。
    - raspi/sonar_radar.py: is_red()をis_green()に変更
    - mujoco_model/sonar_radar.xml: base_red_geomのrgbaを緑相当に変更
    (HSV変換でhue≈167、実機実測のhue158〜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
    [sonar_radar.xml]
2026-08-12 refactor: マーカーのサブモデル名を色ベース→機能ベース(left/right)に統一
    Studio(sonar_radar10.io)でmarker_red/marker_blueをmarker_left/marker_right
    にリネーム。命名基準は「色を検出したときドームがどちらの旋回限界にいるか」
    (マーカー自体の物理設置位置とは対応が逆転する、緑=左限界検出だが物理的には
    右側に設置)。blender_export.pyのオブジェクト参照・出力STLファイル名、
    sonar_radar.xmlのmesh asset名・geom名を追従させ、Blenderのヘッドレス実行で
    STL再生成・MuJoCoでの読み込みを確認済み。studio_to_mujoco.mdに命名基準の
    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
    [bevel_gear_12.stl, bevel_gear_36.stl, obstacle_wall_a.stl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]
2026-08-12 docs: Additional Library Pathの誤記(Studio.io→Stud.io)を修正
    studio_to_mujoco.mdに記載のカスタムパーツパスが実際のフォルダ名と
    異なっており(存在しないディレクトリを指定)、Blenderインポート時に
    モーターローター等のカスタムパーツが無言でスキップされる不具合の
    原因になっていた。実際のフォルダ名(~/.local/share/Stud.io/CustomParts/)
    に修正した。
2026-08-12 fix: sonar_radar10.io/.blendを別Mac由来のカスタムパーツ取り込み成功版に差し替え、STL再生成
    このMacではBlenderのカスタムパーツ(モーターローター等)取り込みが原因不明の
    理由でうまくいかなかったため、別のMacで同じ設定により正常に取り込めた
    sonar_radar10.io/.blendに差し替えた(marker_left/marker_rightの命名は
    維持されていることを確認済み)。差し替え後のBlenderファイルに対して
    blender_export.pyを再実行し、bevel_gear_12(カスタムパーツ含む)が
    NOT FOUNDなく正常収集されたことを確認、STLを再生成した。MuJoCoでの
    読み込みも確認済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
    [bevel_gear_12.stl, bevel_gear_36.stl, obstacle_wall_a.stl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]
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
